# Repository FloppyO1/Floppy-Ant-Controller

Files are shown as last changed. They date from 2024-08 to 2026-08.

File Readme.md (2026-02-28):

# F.A.C. V2 - Floppy Ant Controller

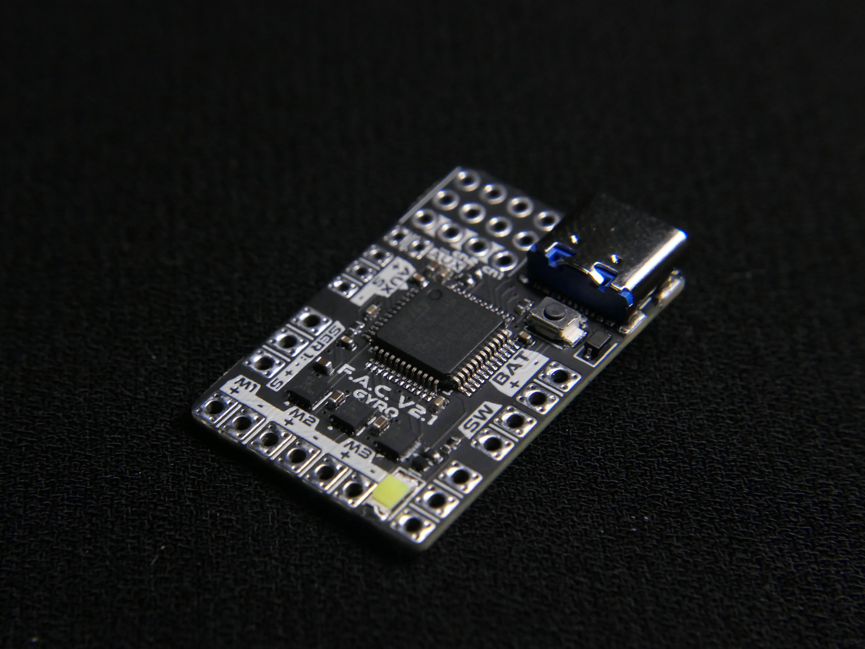
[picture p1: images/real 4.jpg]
FAC V2 front
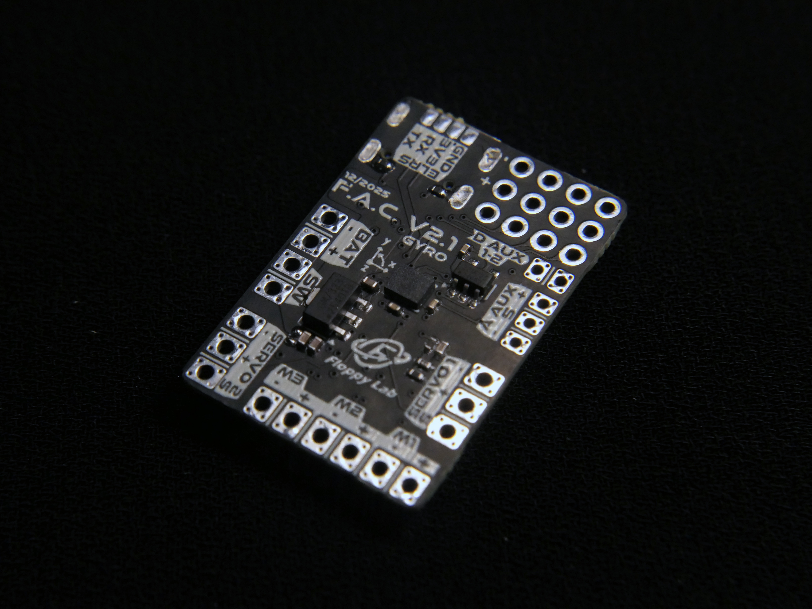
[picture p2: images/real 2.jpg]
FAC V2 rear
 

**F.A.C. V2** is an advanced control board specifically designed for combat robots (such as the Antweight category). Created by **Floppy Lab™**, it serves as a high-performance, highly customizable alternative to the Malenki-nano, offering professional features at a competitive price point.

## 🚀 Key Features

- **Full Customization**: All parameters are adjustable via USB using the dedicated [FAC Tool](https://factool.floppylab.it/).

- **Advanced Hardware**: Features a built-in **IMU** (accelerometer and gyroscope) for future firmware updates and advanced control algorithms.

- **Open Source**: Built with a community-first approach, allowing for user modifications and contributions.

- **Robust Safety**: Includes integrated Watchdog timers, Fail-Safe mechanisms, and Battery Cut-Off to protect your hardware.

## 📊 Technical Specifications

- **DC Motor Outputs**: 3 channels (1.8A max, 1000-step resolution, adjustable frequency 100Hz-10kHz).

- **Servo Outputs**: 2 HV channels (powered directly by the battery) with adjustable frequency and pulse width.

- **Inputs**: 2 Digital inputs and 1 Analog input (max 3.3V).

- **Power Supply**: Optimized for 1-2S LiPo batteries (up to 11V max).

- **Compact Form Factor**: 21mm x 31mm; weighs only 2.4g (bare board) 3.6g (with FS2A).

- **Receiver Compatibility**: Supports PWM (up to 4 channels) and PPM (up to 8 channels), ELRS (not implemented yet but ready to run on current hardware).

## 🛠️ Configuration (FAC Tool)

The **FAC Tool** provides a graphical interface for granular control over your robot's behavior:

1. **Mapping**: Freely assign software functions (e.g., Tank Mix) to physical pins on the board.

2. **Mixes & Special Functions**: Easily configure steering mixes or direct links between radio channels and outputs and others like DC servo.

3. **Real-time Telemetry**: Monitor battery voltage, radio signal values, and operational status (Armed/Disarmed/Cut-Off).

## ⚠️ Safety Information

- **Reverse Polarity**: The board **does not** have reverse polarity protection. Ensure the battery is connected correctly to avoid permanent damage.

- **Activation**: For safety, the FAC will not activate until it detects a valid signal from your receiver.

- **Battery Management**: Always configure the Battery Cut-Off to prevent over-discharging your LiPo cells.

## 📂 Project Structure

- `/FIRMWARE V2`: Firmware source code and binaries.

- `/docs`: Full English and Italian manual.

- `/HARDWARE V2`: Design files.

- `/TOOLS`: Usefull python tools, and the FAC jingle composer.

## 📦 Manufacturing

If you want to manufacture them by yourself you can do it directly from this link: [click here](https://www.pcbway.com/project/shareproject/Floppy_Ant_Controller_FAC_V2_The_Advanced_Control_Board_for_Combat_Robotics_f4803c5c.html)

Using this link you automatically help me with a small tip, without any additional costs. Thanks!

## 📩 Support & Feedback

Developed by **Floppy Lab™**. For suggestions, bugs, or feedback:

- **Email**: thefloppylab@gmail.com

- **Instagram**: [@the_floppy_lab](https://www.instagram.com/the_floppy_lab)

- **YouTube**: [@floppylab](https://www.youtube.com/@floppylab)

- **Website**: [www.floppylab.it](https://www.floppylab.it)

- **Support Me**: [PayPal](https://www.paypal.com/paypalme/FloppyLab)

---

*© 2026 The Floppy Lab™. All rights reserved.*

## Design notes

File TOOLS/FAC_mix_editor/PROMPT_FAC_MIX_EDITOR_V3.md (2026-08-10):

# F.A.C. Mix Editor — work order V3

**The robot stops being two numbers and becomes a machine you lay out.** A chassis
outline you draw, wheels you place and orient, an IMU that sits somewhere on it,
and a planar kinematic model that reads all of that instead of the two-sided
unicycle of §8.

Three changes to `TOOLS/FAC_mix_editor/FAC_mix_editor.html`. **No firmware change,
no generated-code change** — the `.c`/`.h` of every preset must come out
byte-identical, and that is a gate, not an aspiration.

Read `CLAUDE.md` in this folder first. Every invariant in it still holds unless
this document overrides it explicitly, and it overrides exactly one: the robot's
kinematics (§2) and the shape of `P.sim.robot` that goes with it.
`PROMPT_FAC_MIX_EDITOR_V2.md.old` is the previous work order, shipped; §8 in it is
the model this document replaces.

---

## Ground rules

- **Still one file.** No build step, no npm, no CDN, no font, no network call. It
  must keep working from `file://` with the console clean.
- **No second implementation.** This applies to the new solver too: the yaw-rate
  readout, the renderer's slip arrows and the simulator all call **the same
  `solveTwist()`**. A closed-form `maxSpeed / track` displayed next to a machine
  the solver disagrees with is the exact bug this rule exists to prevent.
- **No float in the graph math.** The float boundary count does not change: a
  gamepad axis in `PAD.padToStage0()`, and the robot's physical state in
  `SIM.robotImuCounts()`. The new model makes the second one richer, not looser —
  everything still dies in the same `Math.round` + int16 clamp, and the self-test
  still sweeps it.
- **The sensor model is not touched.** `SIM.sensorOffsets()`, the four noise/offset
  fields and their ODR hold stay exactly as they are. They now apply to counts
  produced by a better physical model; that is all.
- **The self-test is the contract.** Export stays blocked while it has not run or
  has a failure. Every § below adds assertions.
- **Keep the section banners.** The geometry and the solver get their own,
  `SECTION: ROBOT MODEL`, immediately before `SECTION: SIM` — `SIM` is large
  enough already, and the solver is pure and belongs where it can be read alone.
- Tabs, English identifiers and UI text, comments that say *why* and cite
  `file:line` of the firmware wherever they encode firmware behaviour.

---

## Decisions already taken — do not re-litigate

These came out of the design conversation. They are settled; if the implementation
finds one of them impossible, say so and stop, do not quietly pick the other side.

1. **The physics reads the wheels.** Not a drawing that decorates the old model.
2. **There is no wheel *type*.** A wheel has a **lateral grip** in `0…1`: `1` is a
   normal tyre, `0` is an omni/mecanum roller, in between is a track that scrubs.
   The omni case and the skid-slip case are the same parameter and must not become
   two.
3. **A wheel's steering angle may come from a servo row** of the mapper, so it
   changes while the mix runs.
4. **Servos are markers.** Position, mapper row, label, live value. No arm that
   rotates, no contribution to the motion. A wheel steered by a servo (3) is a
   property of the *wheel*, not a drawn servo.
5. **The IMU has a position on the chassis**, and off the centre of rotation it
   reads the centripetal and tangential terms that position implies.
6. **The chassis is a free polygon.** The body origin is the user's `(0,0)`, the
   point their coordinates are relative to — deliberately *not* the polygon
   centroid, which would slide the machine out from under them every time they
   moved a vertex.
7. **Both editors**: numbers in the Robot tab are the truth, dragging on the view
   is a shortcut onto the same fields.
8. **The three-motor-row ceiling stays** (`fac_settings.c:103-107`). The editor may
   describe a machine the firmware cannot drive today — a four-wheel mecanum needs
   four independent motor rows and there are three — and it must **say so** where
   the user picks the link, not hide it.

---

## Phases and order of work

**§1 → §2 → §3** in one commit each, in this order, and **stop after each one**.

- **§1 Model and migration.** Data model, migration, defaults, and every existing
  call site moved onto the new fields. Nothing visible changes.
- **§2 Kinematics, the IMU at a position, and the renderer.** The machine becomes
  real, and you can see it.
- **§3 The editors.** Numeric table, then dragging on the view.

§1 and §2 are fully verifiable headless. §3 is pointer interaction and **must be
checked in a browser by the user before it is called done** — `CLAUDE.md` records
what that costs when it is skipped.

---

## §0 — Verification protocol

`CLAUDE.md` § *Verifying a change without a browser* is the recipe: build the
throwaway node harness in the scratchpad, delete it afterwards, nothing
test-shaped gets committed. Re-read it rather than reinventing it — it lists the
four gotchas of the pure-section slice, the trap where an extracted function
missing a free variable silently does nothing, and the `Proxy` canvas smoke test.

This work order adds three gates on top of it:

- **The two standing regression gates are mandatory at every §**: the generated
  `.c`/`.h` of every preset diffed against `git show HEAD:...` with the
  `FAC_MIX_EDITOR_PROJECT` trailer stripped — **they must be identical, all 16
  files, at all three §** — and the `$('#id')`-versus-markup check (`selbox` is the
  known false positive).
- **Every new assertion gets mutation-tested.** Break what it covers on purpose,
  see it go red, put it back. An assertion that compares a value against the
  default it was derived from is not an assertion.
- **The kinematics is checked against closed forms, not against itself.** The
  three below are the acceptance core of §2 and are written out there in full:
  two parallel wheels reproduce today's numbers *exactly*; a four-wheel skid turns
  by the closed form `(sR−sL) / (2b + 2·g·a²/b)`; and an IMU at radius `r` on a
  machine spinning on the spot reads `ω²r` pointing at the centre.

---

## §1 — The model: a chassis, wheels, devices, an IMU

### The new `P.sim.robot`

```js
robot: {
    maxSpeedCms: 120,             /* ground speed of a wheel at full stick */
    shape: [[10,8],[10,-8],[-10,-8],[-10,8]],   /* cm, body frame, the outline */
    wheels: [                     /* order is the display order, nothing else */
        { x: 0, y: 7, deg: 0, grip: 1, link: 'M1', steer: '', steerDeg: 30, r: 3.5 }
    ],
    devices: [ { x: 8, y: 0, link: 'S1', label: '' } ],   /* markers only */
    imu: { x: 0, y: 0 },
    /* unchanged from §8 and the sensor model */
    imuSource, gyroNoise, accelNoise, gyroBias, accelBias, viewCm, follow, trail
}
```

A wheel: `x, y` cm in the body frame; `deg` its resting steering angle, `0` =
pointing forward; `grip` the lateral grip `0…1`; `link` the mapper row that drives
it, `''` for an undriven wheel (castor, idler, a trailing wheel that only carries
weight); `steer` a mapper row whose value steers it, `''` for a fixed wheel;
`steerDeg` the travel at full deflection; `r` the drawn radius.

**Removed**: `lenCm`, `widCm`, `trackCm`, `kin`, `left`, `right`, `leftB`,
`rightB`. Everything that read them moves onto the geometry:

- `robotScale()`'s auto-fit floor used `max(lenCm, widCm)` → a `chassisBounds()`
  helper over `shape`.
- the renderer's rectangle → the polygon.
- `SIM.sideDrive()` / `SIM.sideValue()` disappear; `solveTwist()` replaces them.
- the *max yaw* readout stops being `maxSpeed / track` and calls the solver (§2).

### Migration — and the one place it deliberately changes behaviour

`migrateProject()` stays pure and keeps building onto an untouched
`blankProject()`. It synthesises the new fields from the old ones:

- `shape` ← the rectangle `lenCm × widCm`, four vertices, centred on the origin.
- `imu` ← `{x: 0, y: 0}`.
- `wheels` ← from `kin`, `left`, `right`, `leftB`, `rightB`, at
  **`y = ±trackCm/2`** — the old physics used `trackCm` and nothing else, so this
  is what keeps an old project's numbers intact — with `deg: 0`, `grip: 1`,
  `steer: ''`.
  - `kin: 'diff'` → two wheels at **`x = 0`**. The result is *bit-for-bit* the old
    model, and the self-test asserts exactly that.
  - `kin: 'skid'` → four wheels at `x = ±0.22·lenCm`, which is where the old
    renderer drew them.
- any mapper row that was linked but not a drive side → a `devices` marker.

**A migrated four-wheel skid turns more slowly than it used to, and that is a
correction, not a regression.** The old model had no notion of a wheelbase at all:
four wheels on a rigid frame *do* resist yaw, in proportion to how far apart they
are along the machine. The self-test must pin the new value to the closed form of
§2, and the Robot tab must say it once, where the grip field is. Do not "fix" this
by migrating skid wheels to `x = 0`: that would hide a real property of the
machine to protect a number that was wrong.

### Done when

- `migrateProject()` is still pure and still merges onto defaults it never writes
  into; a partial `robot` block still defaults every field it omits.
- A schema-2 file with `kin: 'diff'` produces, over a 300-step scripted run, the
  **identical** pose string and the identical IMU counts as `git show HEAD:` does
  for the same file.
- A schema-1 file (no `sim.robot` at all) still loads and drives.
- Both standing gates pass.

---

## §2 — The kinematics, the IMU at a position, the renderer

### The solver

Body frame X forward, Y left, Z up — unchanged, and it is still a statement about
how the board is *mounted* (`enum AXIS`, `LSM6DS3.h:143-147`).

The body twist is `ξ = (vx, vy, ω)`. A wheel `i` at `r = (x, y)` with steering
angle `α` has contact velocity `u = (vx − ω·y, vy + ω·x)`, and two axes of its
own: rolling `d = (cos α, sin α)`, lateral `n = (−sin α, cos α)`.

Two weighted residuals per wheel:

```
rolling   (u·d − s)²  weight 1,     only for a wheel with a drive link
                                    s = deviceValue(link)/V_MAX * maxSpeedCms
lateral   (u·n)²      weight grip,  every wheel
```

with

```
a_roll = ( cos α, sin α,  x·sin α − y·cos α )     b = s
a_lat  = (−sin α, cos α,  x·cos α + y·sin α )     b = 0
```

Minimise the sum: the normal equations `M ξ = c`, `M = Σ w·a·aᵀ` (symmetric 3×3),
`c = Σ w·a·b`. Solve by explicit Cramer on the 3×3 — no library, no iteration —
with a **Tikhonov ridge `λ` added to the diagonal** so that a machine with no
wheels, one wheel, or grip `0` everywhere still yields a finite twist instead of
dividing by a zero determinant. The ridge is load-bearing, not defensive: a
two-wheel machine at grip `0` genuinely leaves `vy` unconstrained. Document the
chosen `λ` and assert that every degenerate layout still integrates finitely — the
renderer's smoke test throws on a non-finite coordinate and that is the point.

`solveTwist()` is **pure**: layout and commands in, `(vx, vy, ω)` plus the per-wheel
residuals out. `integrateRobot()` calls it and keeps everything else it does —
still after `runGraph()`, so a pass still reads the counts of the previous
millisecond.

### The three closed forms that must hold

**Two parallel wheels at `x = 0`, `y = ±b`, grip 1.** `M` comes out diagonal,
`(2, 2, 2b²)`, `c = (sL+sR, 0, b(sR−sL))`, so

```
vx = (sL+sR)/2      vy = 0      ω = (sR−sL)/(2b) = (sR−sL)/track
```

which is §8's model exactly. **This is the first assertion to write and the last
one to let fail.**

**Four wheels at `x = ±a`, `y = ±b`, grip `g`, all forward.** The lateral rows add
`4·g·a²` to `M[2][2]` and nothing else, so

```
ω = (sR − sL) / (2b + 2·g·a²/b)
```

The lateral grip fights the yaw with a term in the **wheelbase squared** — which
is exactly why a long tracked machine turns worse than a short one, and it is the
sentence the Robot tab should carry. `g = 0` returns the two-wheel answer.

**An omni wheel is `grip = 0`** and nothing else: its lateral row vanishes, the
machine gains a `vy`, and the same solver covers mecanum with no special case.

### The slip readout

The residuals are the slip, and they are already computed:
`u·n` per wheel is how fast that contact patch is being dragged sideways (cm/s),
`u·d − s` is how much it is spinning or being dragged along its own axis. Both are
reported per wheel; the renderer draws the lateral one as a short arrow at the
contact patch, and the panel shows the largest of them. Nothing is invented here —
if a number is not a residual of the solve, it does not go on screen.

### The IMU at a position

With the twist and its derivative, the accelerometer at `r = (x, y)` reads

```
a_x = v̇x − ω·vy − α·y − ω²·x
a_y = v̇y + ω·vx + α·x − ω²·y
```

where `α = dω/dt`. At `r = 0` with `vy = 0` this is `(v̇x, ω·vx)`, which is §8's
model — so the general form *contains* the old one and must be shown to.

`v̇x`, `v̇y` and `α` are all difference quotients over a 1 ms step, i.e. spikes of
hundreds of g on any stick movement, so **all three** go through the existing
`ROBOT_ACC_TAU` first-order lag, for the reason §8 already documents. Gyro Z is
still `ω`; gyro X and Y are still zero by construction, the sketch still being
planar.

**The analytic check:** spinning on the spot at constant `ω` with the IMU at
radius `r`, once the lag has settled, the accelerometer must read `ω²r` pointing
at the centre of rotation and nothing else. Assert the vector, not the magnitude —
the sign is the half that can be wrong.

### The renderer

`drawRobotView()` keeps its one-renderer-three-homes shape and its early return on
a zero-size host. What changes inside it:

- the chassis rectangle → `shape` as a closed path;
- each wheel drawn at its position, **rotated to its live steering angle**, sized
  by `r`, filled by the drive bar it already draws, with its lateral-slip arrow;
- devices as markers with their label and the value the mapper would send;
- the IMU as a small crosshair where it sits;
- the HUD gains the largest slip; it keeps the sensor-error tag and the view line.

Smoke-test it with the `Proxy` 2D context over the awkward shapes `CLAUDE.md`
lists, plus the new ones: no wheels, one wheel, a two-vertex "polygon", a wheel
100 m off the chassis, grip `0` everywhere, a steering row that is unlinked.

### Done when

- The three closed forms above hold as assertions.
- A `kin: 'diff'` project migrated from HEAD gives an identical 300-step pose
  string and identical IMU counts.
- Degenerate layouts produce finite numbers and the renderer draws them.
- The *max yaw* readout comes from `solveTwist()` and not from a formula.
- Both standing gates pass. **The generated code is still byte-identical.**

---

## §3 — The editors

### Numeric, in the Robot tab

A table per list — wheels, devices, chassis vertices — with add and remove, one
row per item, the fields of §1, and the derived physical readout beside the ones
that have one (a steering travel in degrees, a grip as *tyre / track / roller*).
The Robot tab already owns the simulator's theory and it keeps owning it: the
grip's meaning, the wheelbase-squared sentence, the migrated-skid correction and
the three-motor ceiling live there and nowhere else.

The list rebuild rule of `CLAUDE.md` applies and is the trap to avoid: **build the
shell once and re-render only the rows.** Rebuilding the panel on every keystroke
destroys the input being typed into and takes the focus and the caret with it.

`P.sim` is not on the undo stack — `applySnap()` restores nodes, wires, mode and
instances only — so the layout editor is not undoable either. That is consistent
with every other robot field; do not make this one list the exception.

### Dragging, on the view

Wheels, chassis vertices and the IMU are draggable on the robot canvas, writing
the same fields. Constraints that come from what is already there:

- **The panel drags itself by its header** (`rbDrag()`), and the canvas pans and
  follows. A drag that starts on a handle must be decided *first*, the way the
  editor's mousedown decides a pan before a node drag — get this wrong and moving
  a wheel moves the panel.
- Hit-testing is in world coordinates through the same `robotScale()` mapping the
  renderer uses. One mapping, both directions.
- A drag that starts on nothing is not a wheel drag.
- Grid snap: reuse the existing snap preference if it is meaningful here; if it is
  not, say so in the tab rather than inventing a second snap.

### Done when

- The numeric table survives typing into it — focus and caret intact.
- Every drag writes the same field the table writes, and the table shows it live.
- **Checked in a browser by the user**, on all three panel homes (floating,
  docked right, docked in the tab), with the pane collapsed and re-opened.
- Both standing gates pass.

---

## Appendix A — deliberately not in scope

- **Dynamics.** Still no mass, no inertia, no traction limit, no motor curve: a
  step on the stick is still a step in ground speed. The lateral grip is a
  *kinematic* weight, not a friction coefficient, and the Robot tab must not let
  anyone read it as newtons. The "illustrative, a kinematic sketch" caveat stays
  on screen.
- **A fourth motor row.** Out of scope here; it is a firmware change. The editor
  describes the machine, warns, and does not pretend.
- **Wheel radius as a gearing.** `r` is drawn size only. Ground speed comes from
  `maxSpeedCms` as it always has.
- **Suspension, camber, wheels off the ground.** Every wheel is in contact.
- **Undo for the layout.** See §3.

## Appendix B — what must not move

Checked at every §, and the first three are the ones that end the work if they
break:

1. The generated `.c`/`.h` of every preset, byte for byte.
2. The two float boundaries, and the int16 clamp at the second one.
3. A `kin: 'diff'` project's pose and IMU counts, against HEAD.
4. The sensor model: gaussian noise held at the 416 Hz ODR, per-run unit-drawn
   offsets, and `robotImuCounts()` pure and deterministic.
5. `migrateProject()` pure, building onto defaults it never writes into.
6. The view as a fixed window on the ground, pixels only.
7. One copy of each explanation: block theory in the *Blocks* tab, simulator
   theory in the *Robot* tab, shortcuts in the help modal.

## Suggested commit messages

```
mix editor: §1 the robot becomes a layout - chassis, wheels, devices, IMU position
mix editor: §2 planar kinematics from the wheels, IMU off-centre, new renderer
mix editor: §3 the layout editors - numeric table and dragging on the view
```

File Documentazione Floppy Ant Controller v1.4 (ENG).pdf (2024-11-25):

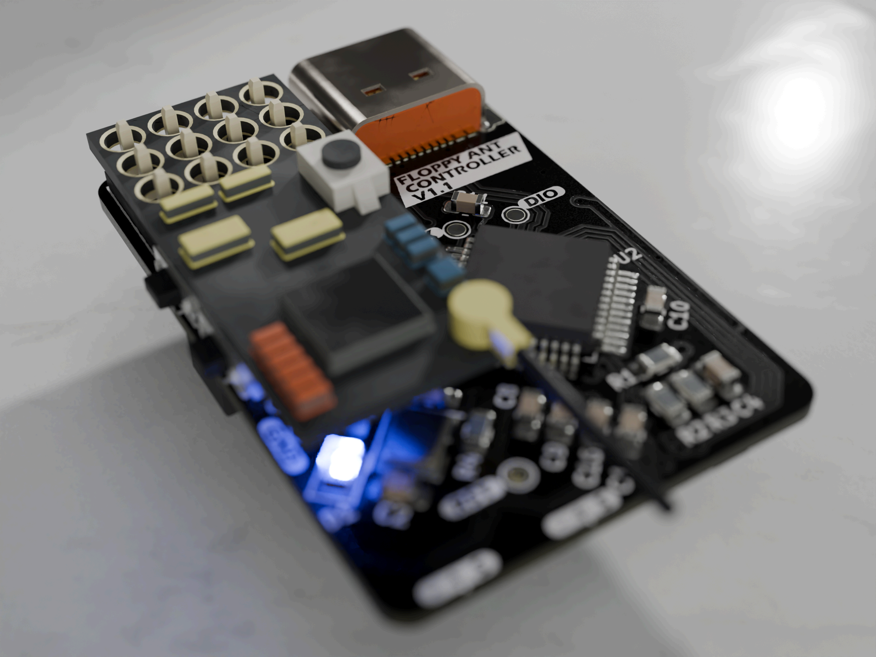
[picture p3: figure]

# Floppy Ant Controller V1.3

### last update 08/2024

─

## This is the documentation in which the functions and methods of use of the Floppy Ant Controller (version

1.3) will be explained.
rev: 1.4 | thefloppylab@gmail.com

Definitions | 2
Overview | 2
Specifications | 2
Connections, buttons and LEDs | 3
Settings and FAC Settings Tool 2.0 | 4
Settings | 4
Connection to PC/smartphone with Serial Monitor | 5
Composition of a command | 5
Changing settings with the FAC Settings Tool 2.0 | 6
FAC capabilities and limitations | 7
More information | 8
rev: 1.0 thefloppylab@gmail.com | 1

## Definitions

1. FAC: Short for Floppy Ant Controller.
2. Tank mix: mixing of the channels to move the wheels with the same logic as the tracks of a tank.
3. BEC: alternative power source, in fact it is a buck converter that lowers the voltage from the battery (2S) down to 5V (3A peak maximum).
4. Pad: where wires can be soldered to make the various electrical connections.

## Overview

In this document you will find all the information necessary to use the Floppy Ant Controller version 1.3.
The methods of use are almost the same for all versions, there are only some variations in the settings and the position of the connection points of the external components.
The FAC has been designed to combine perfectly with the FS2A receivers, excellent for being associated with the economical FlySky-i6 and FS-i4 radio controls, so as to also be accessible for those who do not already have more advanced radio systems.
Obviously no one forbids connecting other types of receivers, the important thing is that they have a PPM or PWM output, this limit is currently dictated by the firmware and part of the hardware.
To make it easy to use, a PC program called FAC Settings Tool (https://github.com/FloppyO1/Floppy-Ant-Controller/blob/main/SOFTWARE/FAC%20Settings%20Tool%202.0.exe) which allows you to easily modify, export and import all the settings of the Floppy Ant Controller.

## Specifications

- 3x DC motor drivers (200 speed steps).
- 2x servo outputs (one of which can be selected with a solder jumper whether 5V or HV from battery).
- Servo output signal frequency 200Hz.
- BEC 5V, 3A maximum (great for a servo motor).
- 2x expansion ports with possible digital or analog readout (e.g. potentiometers, switches, etc.).
- Support for 1s and 2s batteries.

- Battery voltage reading, with weapon speed limitation threshold and full shutdown threshold (independent).
- Settings can be set via USB with dedicated
software or serial terminal.
- Compatibility with 4 PWM channels and 8 PPM channels.
- Dimensions of 23mm*33mm for a weight of 2.9g (without receiver).

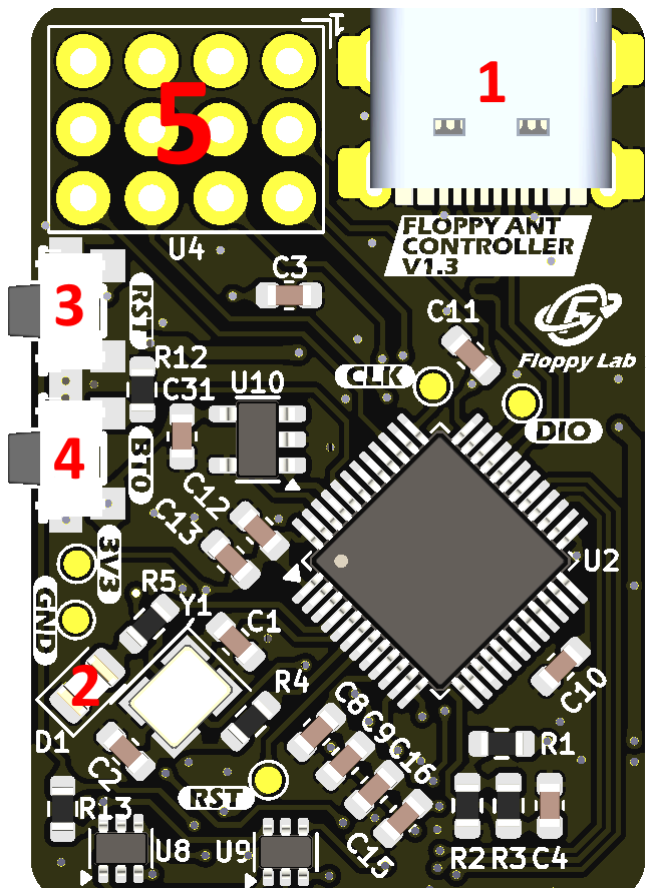
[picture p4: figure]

## Connections, buttons and LEDs

- The USB-C connector

1 allows the connection of the board to the PC to: change the settings, or update the firmware.
- The status LED
2

(D1) indicates what state the FAC is in, therefore whether it is in normal, cutoff or limit operation.
- The RESET buttons

3 e BOOT
4

they are used to start
the bootloader and update the FAC firmware.
- The holes

5 which form a 4*3 matrix, are the ones where the receiver must then be soldered.
- In the pad

6 with the Li-Po label, is where the battery cables must be connected.
- In the SW pad
7

the main switch must be connected, it completely disconnect the battery from the rest of the circuit.
- The pads M1
8

, M2
9

, M3

10 are connected to the DC motor drivers, the outputs have the maximum voltage of the battery, and a supported current of 2A (DRV8838 driver).
- At the bottom are the servo pads
11

, the left one
allows you to choose the output voltage of the power supply, between 5V (from the BEC) and VBAT (directly from the battery), by soldering the jumper

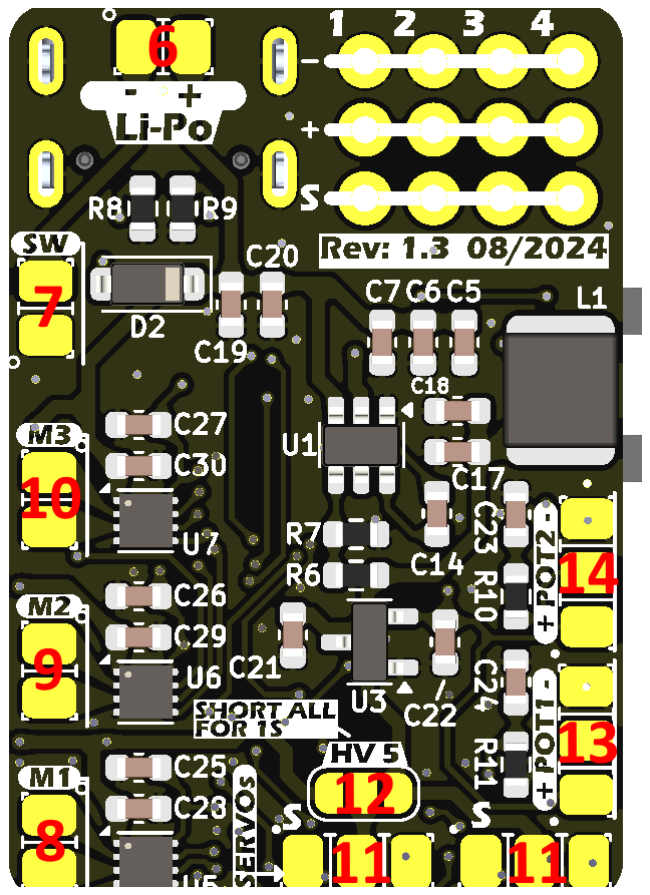
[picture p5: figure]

12 a little higher. The other servo output is only 5V. Both have a 0-5V logic signal.
- Pads POT1

13 and POT2

14 allow you to connect external potentiometers or switches to implement additional functions such as controlling the position of an arm.

## Settings and FAC Settings Tool 2.0

The board’s functionality can be changed by connecting the FAC via USB-C to your PC or smartphone and changing its settings.
The FAC settings are saved in an EEPROM memory, so once the power is disconnected they remain stored, so it is not necessary every time change them when turned on the FAC.

## Settings

Below are all the commands (i.e. settings) and their descriptions in a table.
COMMAND (with default values) | Valid Values | DESCRIPTION
TH2CH>2 | 1 - 8 | Channel assignment to the throttle
ST2CH>4 | 1 - 8 | Channel assignment to steering
WP2CH>3 | 1 - 8 | Channel assignment to the weapon
S12CH>6 | 1 - 8 | Channel assignment to servo output 1
S22CH>1 | 1 - 8 | Channel assignment to servo output 2
ARM2CH>5 | 1 - 8 | Arming channel assignment
M1REV>1 | 0, 1 1 | Reverses motor 1
M2REV>1 | 0, 1 1 | Reverses motor 2
M3REV>0 | 0, 1 1 | Reverses motor 3
S1REV>0 | 0, 1 1 | Reverses servo 1
S2REV>1 | 0, 1 1 | Reverses servo 2
M1ASS>ML | ML, MR, WP 2 | Assign motor 1 the left motor (DC motor)
M2ASS>MR | ML, MR, WP 2 | Assign motor 2 the right motor (DC motor)
M3ASS>WP | ML, MR, WP 2 | Assign motor 3 to the weapon motor (DC motor)
WPDD>0 | 0, 1 1 | The weapon has two directions not just one (DC motor)
TNCON>1 | 0, 1 1 | Tank mix activated
NODISARM>0 | 0, 1 1 | No disarm channels (automatic arming active)
VOLIM>28 (= 2.8V) | 0 - 42 | Weapon speed limiting voltage (voltage per cell)
VCUTOFF>35 (= 3.5V) | 0 - 42 | Total robot deactivation voltage (voltage per cell)
RXPWM>0 | 0, 1 1 | Receiver signal is PWM type (otherwise PPM)
1. In commands with valid values 0 and 1, one is equivalent to “active”, zero equals “deactivated”.
2. With motor assignment commands (MxASS>xx), you cannot assign two motors (M1, M2, M3) with the same type (ML, MR, WP).

READ | Reads the settings from EEPROM and prints them on the serial monitor (if it is sent it overwrites the changes made)
SAVE | Save all settings in EEPROM
CON | It does nothing and is only used for the FAC Settings Tool

## Connection to PC/smartphone with Serial Monitor

Commands can be sent via serial after connecting to the FAC with a serial monitor. This method allows you to set all the values to your liking, though non no check is made that the entered value is valid, therefore use this method with caution when changing settings. You can connect via PC with any serial monitor software (such as Termite, (https://translate.google.com/website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) or that of Arduino IDE), you just need to connect the USB, select the correct port and a baud rate to your liking (the FAC adapts accordingly). Once connected you can send commands.
The same thing applies to the smartphone, you can download an application that manages serial communication (such as Serial USB Terminal, (https://translate.google.com/website?sl=it&tl=en&hl=it&client=webapp) excellent because it allows you to save predefined commands) and connect to the FAC as described before. If it doesn't recognize your board, it's most likely because the cable/adapter you used is not OTG.

## Composition of a command

A command is made up of two parts: the first is the type, the second the value. They are separated by the '>' character. For example, if we want the tank mix throttle to be connected to channel 3 of our radio control, we must send: TH2CH>3.
If the FAC understands the command you just sent it responds with “OK”, otherwise with “WHAT??”
To view the settings saved in the FAC EEPROM, you can send the READ command. Please note that when this command is sent, the settings you have previously changed are overwritten with those read from the EEPROM.
Once you have changed the settings, to save them simply send the SAVE command and make sure that the OK response appears, which indicates correct receipt of the command.

## Changing Settings with “FAC Settings Tool 2.0”

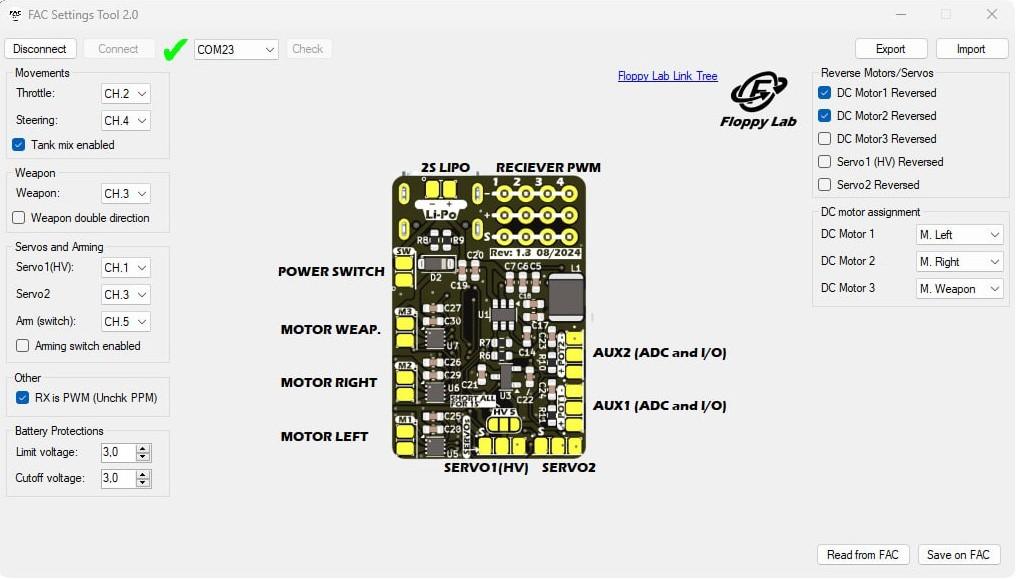
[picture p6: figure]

The FAC Settings Tool 2.0 makes changing FAC settings more intuitive and faster.
On the sides of the application (currently available only for Windows) there are all the settings previously listed in the table. Furthermore, it allows you to export and import settings in a .csv file, so you can save configurations you create, and if necessary they can be easily shared.
1. Once the tool has been opened and the FAC connected to the PC, click on the "Check" button at the top left of the application, and select the correct port with the drop-down menu.
2. Once selected, press the “Connect” button and wait for the green check to appear next to the button you just pressed.
a. If a window appears with an error message, it means that the selected port does not correspond to the FAC, but to some other device. In this case select a different port and press “Connect” again.
3. As soon as the FAC connects all the settings are loaded and the graphics are updated.
4. Now you can change the settings to your liking.
5. Once you are satisfied with the setup, at the bottom right you can click the “Save on FAC” button and wait for the saving to complete.
6. If you want to export or import your settings, simply press the “Export” or “Import” buttons and save the file with the name you prefer.

## FAC capabilities and limitations

The FAC is designed to be used with 150g robots, so the performance of the DC drivers and BEC is limited.
1. The three drivers for the DC motors are designed to operate up to a voltage of 12V, and a peak current of 1.9A (the driver used is the DRV8838, the same as Malenki nano) (https://github.com/MarkR42/malenki-nano.git) so they are great for running N20 motors.
2. The status LED together with the sounds played by the DC motors indicate the status of the board. When the board is working normally, the LED flashes with a period of 1 second. If the board is not armed one of the motors emits a "beep", otherwise no sound is emitted.
3. The card allows you to set arming, i.e. if the robot is not armed all its functions are deactivated (wheels and weapon stopped, servo position 0). If arming via the remote control channel is not active (activated from settings), the FAC is already armed as soon as it is switched on and cannot be disarmed.
If a dedicated channel is used for arming, the FAC can be disarmed whenever you want.
4. The FAC integrates the battery voltage reading. The reading may be inaccurate due to component tolerances.
Two (independent) thresholds can be set which are activated 10 seconds after the battery voltage drops below them:
a. The first (Limit) limits the speed of the weapon (only if DC motor) to 50% of the speed, so as to extend the battery life during the fight.
b. The second (Cut-Off) completely disables the robot, this threshold is usually very low, and serves to preserve the health of the batteries. When the robot is in Cut-Off the status LED flashes quickly.
5. The BEC is effectively a buck converter, which is designed to withstand a maximum current of 3A (better to stick to a maximum of 2.5A). Therefore, when servo motor outputs are used, I strongly recommend not using two servos powered by the BEC and not connecting ESCs with BLDC motors, as this may result in malfunctions and breakage of the BEC and the rest of the board, making it unusable.
To overcome this problem, you can use a 5V servo (i.e. from the BEC) and an HV servo by soldering the jumper in the marked part.

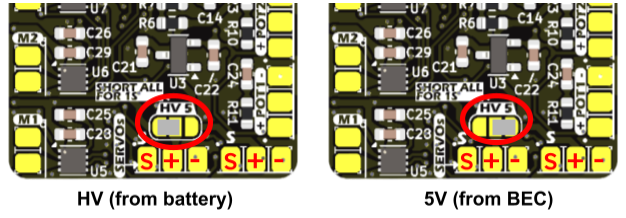
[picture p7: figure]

6. The FAC can be powered at a maximum voltage of 8.4V, therefore a 2S battery. This limitation is due to the maximum voltage of the DC motor drivers, and the battery voltage reading.
7. To use a FAC with a 1S battery, you can short (as marked on the board) the three servo motor voltage selection pads, so the input and output of the BEC are shorted, so the BEC stays off. Be very careful not to power more than 5V when using this configuration, otherwise the board will burn out.
8. Be careful, when the FAC is connected to the PC all systems are also active, including the DC drivers and servo motors.

## Firmware update

- To update the FAC firmware, you need to use a tool called STM32CubeProgrammer downloadable from the ST Microelectronics (https://github.com/FloppyO1/Floppy-Ant-Controller/blob/main/SOFTWARE/FAC%20firmware%201.3.elf) website (I recommend downloading version 2.15.0).
- Once you have downloaded the Cube Programmer, on the project GitHub page, inside the “SOFTWARE” folder, you need to download the “FAC firmware.elf” (https://github.com/FloppyO1/Floppy-Ant-Controller/blob/main/SOFTWARE/FAC%20firmware%201.3.elf) file which is the file to upload to the FAC.
- Once you have downloaded the .elf file, open Cube Programmer and connect the FAC with a data cable to the PC.
- Now we activate the FAC bootloader, to do this you need to press both buttons on the side of the FAC, and first release the RESET

1 button, then you can also release

the other one
2

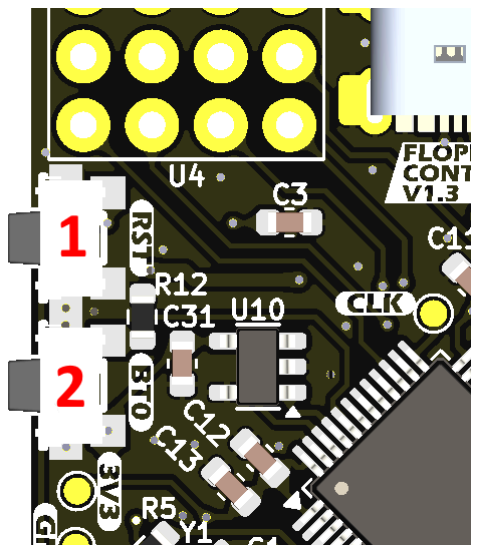
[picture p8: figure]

- The green light on the FAC should no longer light up, and you should hear the classic sound of inserting a USB device.
- On CubeProgrammer select USB from the drop-down menu at the top right next to the “Connect” button, then click the refresh button to find the port to connect to, it should appear next to where it said “No DFU…”. After finding it, press Connect and wait for some writing to appear in the middle of the screen.

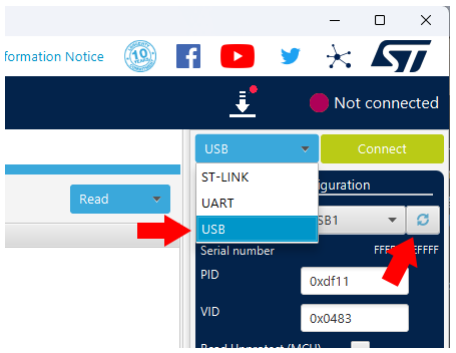
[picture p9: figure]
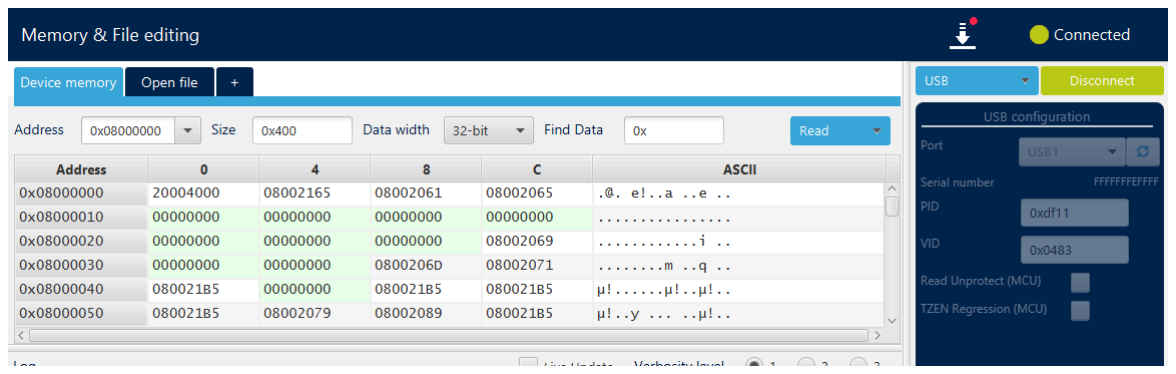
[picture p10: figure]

- Press the second icon on the left of the screen, and then by clicking the “Browse” button select the “FAC firmware.elf” file that you downloaded earlier. Add the check mark on “Verify programming” and “Run after programming”.

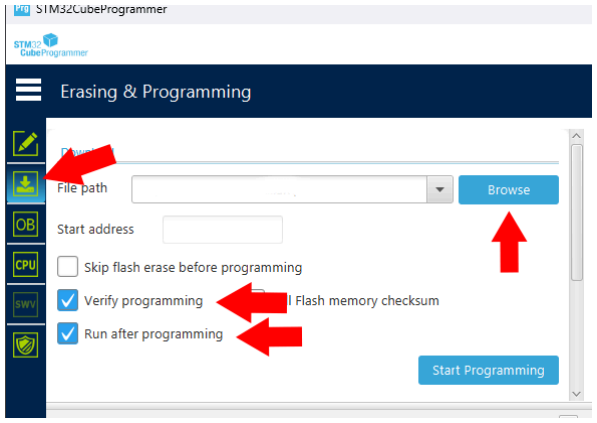
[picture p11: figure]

- Now all that remains is to press the “Start Programming” button, once the program has finished loading the FAC should restart and the light will start flashing slowly again.
Your FAC firmware is now updated to the latest version available!

## More information

The entire project is open source, and you can find all the files on this GitHub page. (https://github.com/FloppyO1/Floppy-Ant-Controller) For any questions or requests do not hesitate to send an email to: thefloppylab@gmail.com.

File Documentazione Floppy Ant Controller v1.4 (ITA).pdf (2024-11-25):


# Floppy Ant Controller V1.3

### ultimo aggiornamento 08/2024

─

## Questa è la documentazione in cui verranno spiegate le funzionalità e la modalità d’uso della Floppy Ant

Controller (versione 1.3).

rev: 1.4 | thefloppylab@gmail.com

Definizioni | 2
Panoramica | 2
Specifiche | 2
Connessioni, pulsanti e LED | 3
Impostazioni e FAC Settings Tool 2.0 | 4
Impostazioni | 4
Connessione al PC/smartphone con Monitor Seriale | 5
Composizione di un comando | 5
Modifica delle impostazioni con il “FAC Settings Tool 2.0” | 6
Aggiornamento del firmware | 7
Capacità e limitazioni della FAC | 7
Altre informazioni | 8
rev: 1.0 thefloppylab@gmail.com | 1

## Definizioni

1. FAC: abbreviazione di Floppy Ant Controller.
2. Tank mix: mixing dei canali per muovere le ruote con la stessa logica dei cingoli di un carro armato.
3. BEC: fonte di alimentazione alternativa, di fatto è un buck converter che abbassa la tensione dalla batteria (2S) fino a 5V (3A picco massimi).
4. Pad: piazzola dove si possono saldare dei fili per effettuare le varie connessioni elettriche.

## Panoramica

In questo documento troverete tutte le informazioni necessarie per poter utilizzare la Floppy Ant Controller versione 1.3.
Le modalità d’uso sono pressoché uguali per tutte le versioni, ci sono solo alcune variazioni nelle impostazioni e la posizione dei punti di connessione dei componenti esterni.
La FAC è stata pensata per combinarsi perfettamente con i ricevitori FS2A, ottimi per essere associati agli economici radiocomandi FlySky-i6 e FS-i4, così da essere anche accessibile per chi non è già in possesso di sistemi radio più avanzati.
Ovviamente nessuno vieta di collegare altri tipi di ricevitori, l’importante è che abbiano una uscita PPM o PWM, questo limite è per ora dettato dal firmware e parte del hardware.
Per renderla facile da usare, è stato realizzato un programma per PC chiamato FAC Settings Tool (https://github.com/FloppyO1/Floppy-Ant-Controller/blob/main/SOFTWARE/FAC%20Settings%20Tool%202.0.exe) che permette di modificare, esportare e importare agevolmente tutte le impostazioni della Floppy Ant Controller.

## Specifiche

- 3x driver per motori DC (200 passi di velocità).
- 2x uscite servo (una delle quali può essere selezionata con un ponticello a saldare se 5V o HV dalla batteria).
- Frequenza del segnale delle uscite servo 200Hz.
- BEC 5V, 3A massimi (ottimi per un servo motore).
- 2x porte di espansione con possibile lettura digitale o analogica (es. potenziometri, interruttori, ecc.).
- Supporto per batterie da 1s e 2s.

- Lettura della tensione della batteria, con soglia di limitazione della velocità dell'arma e soglia di spegnimento completo (indipendenti).
- Le impostazioni possono essere impostate tramite
USB con software dedicato o terminale seriale.
- Compatibilità con 4 canali PWM e 8 canali PPM.
- Dimensioni di 23mm*33mm per un peso di 2,9g (senza ricevente).


## Connessioni, pulsanti e LED

- Il connettore USB-C

1 permette la connessione della scheda al PC per: modificare le impostazioni, oppure l’aggiornamento del firmware.
- Il LED di stato
2

(D1) indica in che stato è la FAC, quindi se è in operazione normale, cutoff o limit.
- I pulsanti di RESET

3 e BOOT

4 servono per poter
avviare il bootloader e aggiornare il firmware della FAC.
- I fori

5 che formano una matrice 4*3, sono quelli dove va poi saldato il ricevitore.
- Nel pad

6 con l’etichetta Li-Po vanno collegati i cavi della batteria.
- Nel pad SW⁷ va collegato l’interruttore generale che scollega completamente la batteria dal resto del circuito.
- Nei pad M1
8

, M2
9

, M3

10 sono collegati ai driver dei motori DC, le uscite hanno come tensione massima quella della batteria, e una corrente supportata di 2A (driver DRV8838).
- In basso si trovano i pad dei servo
11

, il primo
permette di scegliere la tensione di uscita dell’alimentazione, tra 5V (dal BEC) e VBAT
(direttamente dalla batteria), saldando il ponticello
12


poco più in sopra. La seconda uscita del servo è soltanto 5V. Entrambe hanno un segnale logico 0-5V.
- I pad POT1

13 e POT2

14 permettono di collegare dei potenziometri o degli interruttori esterni per poter implementare funzioni aggiuntive come il controllo della posizione di un braccio.

## Impostazioni e FAC Settings Tool 2.0

Le funzionalità della scheda possono essere modificate collegando la FAC via USB-C al PC o allo smartphone e modificando le sue impostazioni.
Le impostazioni della FAC sono salvate in una memoria EEPROM, quindi una volta scollegata l’alimentazione rimangono memorizzate, così non è necessario ogni volta cambiarle all’accensione.

## Impostazioni

Di seguito sono riportati in una tabella tutti i comandi (ovvero le impostazioni) e la loro descrizione.
COMANDO (con valori default) | Valori Validi | DESCRIZIONE
TH2CH>2 | 1 - 8 | Assegnazione del canale all’acceleratore
ST2CH>4 | 1 - 8 | Assegnazione del canale allo sterzo
WP2CH>3 | 1 - 8 | Assegnazione del canale all’arma
S12CH>6 | 1 - 8 | Assegnazione del canale all’uscita del servo 1
S22CH>1 | 1 - 8 | Assegnazione del canale all’uscita del servo 2
ARM2CH>5 | 1 - 8 | Assegnazione del canale di arming (attivazione)
M1REV>1 | 0, 1 1 | Inverte il motore 1
M2REV>1 | 0, 1 1 | Inverte il motore 2
M3REV>0 | 0, 1 1 | Inverte il motore 3
S1REV>0 | 0, 1 1 | Inverte il servo 1
S2REV>1 | 0, 1 1 | Inverte il servo 2
M1ASS>ML | ML, MR, WP 2 | Assegna al motore 1 il motore sinistro (motore DC)
M2ASS>MR | ML, MR, WP 2 | Assegna al motore 2 il motore destro (motore DC)
M3ASS>WP | ML, MR, WP 2 | Assegna al motore 3 il motore dell’arma (motore DC)
WPDD>0 | 0, 1 1 | L’arma ha due direzioni non solo una (motore DC)
TNKON>1 | 0, 1 1 | Attivato il tank mix
NODISARM>0 | 0, 1 1 | Nessun canale di arming (arming automatico attivo)
VLIM>28 (= 2.8V) | 0 - 42 | Tensione di limitazione velocità arma (tensione per cella)
VCUTOFF>35 (= 3.5V) | 0 - 42 | Tensione di disattivazione totale del robot (tensione per cella)
RXPWM>0 | 0, 1 1 | Segnale del ricevitore in PWM
1. Nei comandi con valori validi 0 e 1, uno equivale ad “attivo”, zero equivale “disattivato”.
2. Nei comandi di assegnazione dei motori (MxASS>xx), non si può assegnare a due motori (M1, M2, M3) con lo stesso tipo (ML, MR, WP).

READ | Legge da EEPROM le impostazioni e le stampa sul monitor seriale (se viene inviato sovrascrive le modifiche effettuate)
SAVE | Salva tutte le impostazioni in EEPROM
CON | Non fa nulla è utilizzato solo per il FAC Settings Tool

## Connessione al PC/smartphone con Monitor Seriale

Ii comandi si possono inviare via seriale dopo essersi connessi alla FAC con un monitor seriale. Questo metodo vi permette di impostare tutti i valori a vostro piacimento, però non viene effettuato nessun controllo che il valore immesso sia valido, quindi usate con cautela questo metodo per la modifica delle impostazioni.
Potete collegarvi via PC con un qualsiasi software di monitor seriale (come Termite, (https://translate.google.com/website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) oppure quello di Arduino IDE), è necessario solo collegare la USB, selezionare la porta corretta e un baudrate a vostro piacimento (la FAC si adegua di conseguenza). Una volta collegati potete inviare i comandi.
La stessa cosa si applica allo smartphone, potete scaricare una applicazione che gestisce la comunicazione seriale (come Serial USB Terminal, (https://translate.google.com/website?sl=it&tl=en&hl=it&client=webapp) ottima perché permette di salvare dei comandi predefiniti) e collegarvi come descritto prima alla FAC. Se non vi riconosce la scheda, molto probabilmente è perché il cavo/adattatore che avete usato non è OTG.

## Composizione di un comando

Un comando è composto da due parti: la prima è il tipo, la seconda il valore. Esse sono separate dal carattere ‘>’. Per esempio se vogliamo che l’acceleratore del tank mix sia collegato al canale 3 del nostro radiocomando dobbiamo inviare: TH2CH>3.
Se la FAC capisce il comando che avete appena inviato vi risponde con “OK”, altrimenti con “WHAT??”
Per visualizzare le impostazioni salvate nella EEPROM della FAC, si può inviare il comando READ. Fate attenzione che quando viene inviato questo comando, le impostazioni che avete modificato in precedenza vengono sovrascritte con quelle lette dalla EEPROM. Una volta modificate le impostazioni, per salvarle basta inviare il comando SAVE ed assicurarsi che appaia la risposta OK, che indica il corretto ricevimento del comando.

## Modifica delle impostazioni con il “FAC Settings Tool 2.0”


Il FAC Settings Tool 2.0 rende più intuitiva e veloce la modifica delle impostazioni della FAC. Ai lati dell’applicazione (per ora disponibile solo per Windows) sono presenti tutte le impostazioni prima elencate nella tabella. In più permette di esportare e importare le impostazioni in un file .csv, così da poter salvare delle configurazioni da voi create, e in caso di necessità sono facilmente condivisibili.
1. Una volta aperto il tool e collegata al PC la FAC, cliccare sul pulsante “Check” in alto a sinistra dell’applicazione, e selezionare la porta corretta con il menu a tendina.
2. Una volta selezionata premere il pulsante “Connect” e attendere che appaia la spunta verde in fianco al pulsante appena premuto.
a. Nel caso in cui appaia una finestra con un messaggio di errore, vuol dire che la porta selezionata non corrisponde alla FAC, ma a qualche dispositivo. In questo caso selezionate una porta differente e premete ancora “Connect”.
3. Non appena la FAC si connette vengono caricate tutte le impostazioni e vengono aggiornate le grafiche.
4. Ora potete modificare le impostazioni a vostro piacimento.
5. Una volta soddisfatti del setup, in basso a destra potete cliccare il pulsante “Save on FAC” e attendere che il salvataggio venga completato.
6. Se volete esportare o importare le vostre impostazioni è sufficiente premere i pulsanti “Export” o “Import” e salvare il file con il nome che preferite.

## Capacità e limitazioni della FAC

La FAC è pensata per essere utilizzata con dei robot da 150g, per questo le prestazioni dei driver DC e del BEC sono limitate.
1. I tre driver per i motori DC sono progettati per funzionare fino ad una tensione di 12V, e una corrente di picco di 1.9A (il driver usato è il DRV8838, lo stesso della Malenki nano) (https://github.com/MarkR42/malenki-nano.git) quindi sono ottimi per gestire motori N20.
2. Il LED di stato insieme ai suoni riprodotti dai motori DC indicano lo stato della scheda. Quando la scheda funziona normalmente, il LED lampeggia con un periodo di 1 secondo. Se la scheda non è armata uno dei motori emette un “beep”, altrimenti nessun suono viene emesso.
3. La scheda permette di impostare l’arming, ovvero se il robot non è armato tutte le sue funzionalità sono disattivate (ruote e arma ferma, servo posizione 0). Se l’arming tramite canale del telecomando non è attivo (attivabile dalle impostazioni), la FAC non appena viene accesa è già armata e non è possibile disarmarla.
Nel caso in cui si utilizzi un canale dedicato per l’arming, la FAC si può disarmare e armare a piacimento.
4. La FAC integra la lettura della tensione della batteria. La lettura può essere imprecisa causa tolleranze dei componenti.
Si possono impostare due soglie (indipendenti) che si attivano dopo 10 secondi che la tensione della batteria scende sotto di esse:
a. la prima (Limit) limita la velocità dell’arma (solo se motore DC) al 50% della velocità, così da allungare la durata della batteria durante il fight.
b. la seconda (Cut-Off) disabilita completamente il robot, questa soglia è solitamente molto bassa, e serve per preservare la salute delle batterie. Quando il robot è in Cut-Off il LED di stato lampeggia velocemente.
5. Il BEC è di fatto un buck converter, che è progettato per sopportare una corrente massima di 3A (meglio rimanere su massimo 2.5A). Quindi quando vengono utilizzate le uscite dei servomotori, consiglio vivamente di non utilizzare due servo alimentati dal BEC e di non collegare degli ESC con motori BLDC, in quanto si possono avere malfunzionamenti e rottura del BEC e il resto della scheda, rendendola inutilizzabile.
Per ovviare a questo problema, si possono utilizzare un servo alimentato a 5V (ovvero dal BEC) e uno HV saldando il ponticello nella parte segnata.


6. La FAC può essere alimentata ad una tensione massima di 8.4V, quindi una batteria 2S. Questa limitazione è dovuta dalla tensione massima dei driver dei motori DC, e dalla lettura della tensione della batteria.
7. Per utilizzare una FAC con una batteria 1S, si può mettere in cortocircuito (come segnato sulla scheda) i tre pad della selezione della tensione del servomotore, così l’entrata e l’uscita del BEC vengono cortocircuitate, quindi il BEC rimane spento. Fate molta attenzione a non alimentare a più di 5V quando usate questa configurazione, altrimenti la scheda si brucia.

### 8. Fate attenzione, quando la FAC è collegata al PC anche tutti i sistemi sono

attivi, compresi i driver DC che i servomotori.

## Aggiornamento del firmware

- Per aggiornare il firmware della FAC, è necessario utilizzare un tool chiamato STM32CubeProgrammer scaricabile dal sito della ST Microelectronics (https://www.st.com/en/development-tools/stm32cubeprog.html) (consiglio di scaricare la versione 2.15.0).
- Una volta scaricato il Cube Programmer, nella pagina GitHub del progetto, all’interno della cartella “SOFTWARE”, bisogna scaricare il file “FAC firmware.elf” (https://github.com/FloppyO1/Floppy-Ant-Controller/blob/main/SOFTWARE/FAC%20firmware%201.3.elf) che è il file da caricare sulla FAC.
- Una volta scaricato il file .elf, aprire Cube Programmer e collegare la FAC con un cavo dati al PC.

- Ora attiviamo il bootloader della FAC, per farlo bisogna premere entrambi i pulsanti a lato della FAC, e rilasciare per primo il pulsante di RESET
1

, poi si può rilasciare
anche l’altro
2


- La luce verde della FAC non dovrebbe più accendersi, e si dovrebbe sentire il classico suono di inserimento di un dispositivo USB.
- Su Cube Programmer selezionare in alto a destra, in fianco al pulsante “Connect”, “USB” dal menu a tendina, poi sotto cliccare il pulsante aggiorna per trovare la porta a cui connettersi, dovrebbe apparire in fianco dove c’era scritto “No DFU…”. Dopo averla trovata premere su “Connect” e attendere che appaiano delle scritte in mezzo allo schermo.

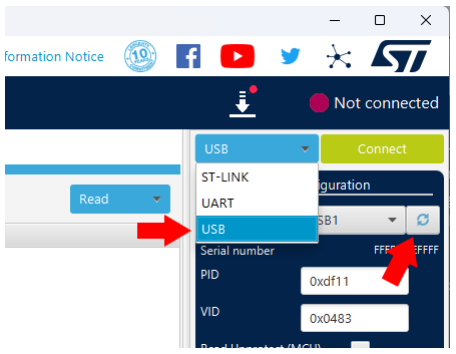
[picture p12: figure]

- Premere sulla seconda icona che si trova sulla sinistra della videata, e poi cliccando sul pulsante “Browse” selezionare il file “FAC firmware.elf” che avete scaricato prima.

Aggiungere la spunta su “Verify programming” e “Run after programming”.


- Ora resta solo premere sul pulsante “Start Programming”, finito di caricare il programma la FAC dovrebbe riavviarsi e la luce riprende a lampeggiare lentamente. Il firmware della vostra FAC è ora aggiornato all’ultima versione disponibile!

## Altre informazioni

Tutto il progetto è open source, e trovate tutti i file su questa pagina GitHub. (https://github.com/FloppyO1/Floppy-Ant-Controller) Per ogni domanda o richiesta non esitate ad inviare una mail all’indirizzo: thefloppylab@gmail.com.

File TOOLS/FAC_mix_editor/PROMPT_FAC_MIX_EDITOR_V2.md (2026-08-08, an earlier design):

# F.A.C. Mix Editor — work order V2

Ten changes to `TOOLS/FAC_mix_editor/FAC_mix_editor.html`, plus one coordinated
firmware fix in the `FIRMWARE V2/FAC-Firmware-V2` submodule.

Read `CLAUDE.md` in this folder first, and `PROMPT_FAC_MIX_EDITOR.md.initial` for
anything this document does not cover. Every invariant in `CLAUDE.md` still holds
unless this document overrides it explicitly, and it overrides exactly one thing:
the channel domain (§1).

**This document has been revised against the firmware sources.** Every `file:line`
below was opened and read, not inferred. Where the first draft of this work order
was wrong about the firmware, the text now states the verified behaviour instead —
see in particular §1 *Output side*, where the originally proposed motor fix
recovered nothing and the servo claim was inaccurate. Appendix A records the
defects found on the way that are deliberately **not** being fixed, and Appendix B
is the complete audit of the old-domain constants that §1 must eliminate.

## Ground rules for all ten items

- **Still one file.** No build step, no npm, no CDN, no font, no network call, no
  telemetry. It must keep working from `file://` with the devtools console clean.
- **No second implementation.** Every block stays a single `def({...})` declaring
  `sim` and `emit` side by side. The new documentation tab (§9) must *derive* its
  content from `NODES` — if it contains one hand-written sentence about a block
  that is already in that block's `help`, it is wrong.
- **No float in the graph math.** There are currently exactly two float boundaries:
  the gamepad axis conversion (`PAD.padToStage0`, ~line 2560) and the illustrative
  robot integrator (`SIM.integrateRobot`, ~line 2459). §8 grows the second one — it
  must still terminate in `Math.round(...)` before any value reaches `SIM.gyro` /
  `SIM.accel`, and a self-test assertion must prove it.
- **The self-test is the contract.** `runSelfTest()` runs at boot, export stays
  blocked while it has not run or has a failure. Every item below that changes
  arithmetic must add assertions, not just avoid breaking the existing ones.
- **Keep the section banners.** New code goes inside the right `SECTION:`, or gets
  its own banner. Do not let the file turn into one blob.
- Tabs for indentation, English identifiers and UI text, comments explaining *why*
  and citing `file:line` of the firmware when they encode firmware behaviour.

## Phases and order of work

**Phase 1 — mandatory:** §1 → §3 → §4 → §5 → §6 → §2 → §7 → §9.
§1 first because it changes the model everything else is validated against; the
canvas interaction fixes (§3-§6) next because they are small and independent; the
two big UI features (§2, §7, §9) after them.

**Phase 2 — deferred:** §8, the live robot view and the IMU closed loop. It is
fully specified at the end of this document so that it does not need to be
redesigned when it is picked up, but it is not part of the phase 1 delivery.

Work in stages: stop after each § for a browser check before starting the next
one. One commit per §.

---

## §0 — Verification protocol

There is no browser in the implementation environment and there must be no test
runner in the repository, so verification happens through a **throwaway node
harness** built in the session scratchpad and never committed.

- Node 24 is available. The harness extracts the pure sections of the HTML
  (`FAC_MATH`, `RECEIVER`, `INTERVALS`, `NODE_CATALOG`, `GRAPH`, `VALIDATE`,
  `CODEGEN`, `SELFTEST`, `PRESETS`) by their `SECTION:` banners, evaluates them
  with minimal stubs for the handful of DOM symbols they touch, and calls
  `runSelfTest()` and `headlessMix()`.
- The harness lives in the scratchpad only. It is a verification aid for the
  implementer, not an artefact: `CLAUDE.md` says no test runner, and that stands.
- Every § below carries a **Done when** block. Those are the acceptance gates; a
  § is not finished until every line of its block has actually been executed, not
  reasoned about.
- The one thing the harness cannot cover is the pointer interaction of §2-§7.
  Those sections' gates are explicitly manual and must be checked in a browser by
  the user before the next § starts.

---

## §1 — Channel domain becomes symmetric: −1000 … +1000

### The problem, precisely

The channel domain is *inconsistent between producers and consumers*, and the
asymmetric mix input is the visible symptom of that.

| stage | file | domain produced/assumed |
|---|---|---|
| capture (PWM) | `fac_pwm_receiver.c:82-84` | `map_uint32(..., 0, RESOLUTION-1)` then clamp to `RESOLUTION-1` → **0…999** |
| capture (PPM) | `fac_ppm_receiver.c:62` | same → **0…999** |
| deadzone | `fac_std_receiver.c:86-127` | maps in from `0…RESOLUTION` and back out to `0…RESOLUTION` → **already written for 0…1000** |
| store | `fac_std_receiver.c:60-67` | clamps to `RESOLUTION-1` → **0…999** |
| mix input | `fac_mixes.c:111-115`, `fac_functions.c:79-83` | `FAC_math_from_range(rx, 0, RESOLUTION)` → **assumes 0…1000** |

Two of the three stages already speak `0…1000`. Only the capture and the store
use `RESOLUTION-1`. That mismatch is what makes a mix input reach `-1000` but
only `+998`.

### Chosen fix — widen the input domain to `0…1000`

Rationale, so it does not get re-litigated: `0…1000` is 1001 values and therefore
has an **exact centre** — `rx = 500` gives `from_range(500,0,1000) = 0` with no
rounding, and the documented identity `mix_input = 2*rx - 1000` holds exactly.
Narrowing the consumer to `0…999` instead would make the stick centre land on
`+1` with the deadzone off, because 1000 values have no exact middle.

**Firmware — input side:**

1. `Core/Src/FAC_Code/fac_std_receiver.c:60-67` — `FAC_std_receiver_SET_channel()`
   clamps to `RECEIVER_CHANNEL_RESOLUTION`, not `- 1`. Replace the `// -1 because
   number 0 is considered` comment with one that states the domain is `0…1000`,
   1001 values, centre 500.
2. `Core/Src/FAC_Code/fac_pwm_receiver.c:82-84` — map to `0, RECEIVER_CHANNEL_RESOLUTION`
   and clamp to `RECEIVER_CHANNEL_RESOLUTION`.
3. `Core/Src/FAC_Code/fac_ppm_receiver.c:62` — same map change. The clamp there is
   commented out already; leave it commented, `map_uint32` bounds the result.
4. **Do not touch the deadzone.** It is already correct for this domain. Two of its
   guards are unreachable dead code — see Appendix A — and they stay as they are.

### Output side — what the first draft got wrong

The first draft claimed the same off-by-one existed mirrored on the output side and
that "full positive travel is unreachable at *both* ends of the chain". That is
**not what the sources say**, and the two fixes it proposed are one unnecessary and
one actively harmful. The verified situation:

**Servo.** `fac_mapper.c:102` produces `FAC_math_to_range(v, 0, SERVO_POSITION_RESOLUTION)`,
i.e. `p = (v + 1000) / 2` over `0…1000`. `FAC_servo_SET_position()`
(`fac_servo.c:30-37`) clamps that to `MAX_SERVO_VALUE = 999`.

- The clamp is **load-bearing, not defensive**. The pulse is
  `p_us = span * position / MAX_SERVO_VALUE` (`fac_servo.c:98`), so a position of
  1000 would produce a pulse *beyond* the configured `max_us`.
  `docs/README_API.md:537` states this explicitly. Do not describe this clamp as
  defensive and do not remove it.
- Full travel is therefore **already reachable**: `v = 998` gives position 999,
  which is exactly `max_us`. The real defect is smaller and different — a
  three-value flat spot at the top, since `v = 998`, `999` and `1000` all land on
  position 999, and a map that is not uniform across the travel.

**Motor.** `fac_mapper.c:75-78` produces `speed = abs(v) * MOTOR_SPEED_RESOLUTION / FAC_VALUE_MAX`,
which is exactly `abs(v)` because both constants are 1000. `FAC_motor_SET_speed()`
(`fac_motors.c:63-68`) clamps it to `MAX_DMA_PWM_VALUE = PWM_STEPS - 1 = 999`
(`DMApwm.h:32`).

- The originally proposed `abs(v) * (MOTOR_SPEED_RESOLUTION - 1) / FAC_VALUE_MAX`
  yields **the same value at full scale** (1000 → 999, exactly as the clamp already
  did) and truncates everywhere below it (500 → 499). It costs the exactness that
  `fac_math.h:28` and `docs/README_MIX_EDITOR_API.md:96` describe as the reason the
  ±1000 scale was chosen, and buys nothing. **Rejected.**
- The actual ceiling is the clamp, and it is a conservative choice in
  `fac_motors.c`, not a hardware limit: `setSoftPWM()` (`DMApwm.c:73-76`) accepts
  `duty == PWM_STEPS` and its full-buffer loop `i < duty` then sets all
  `PWM_STEPS` entries, driving the pin high for the whole period — a true 100 %
  duty. The hardware has been confirmed safe at 100 %.

### Firmware — output side

5. `Core/Src/FAC_Code/fac_mapper.c:102` — servo position becomes
   `FAC_math_to_range(outputLinkedValue, 0, MAX_SERVO_VALUE)`. Write
   `MAX_SERVO_VALUE`, not `SERVO_POSITION_RESOLUTION - 1`: it is the same number
   and it ties the expression to the divisor in `fac_servo.c:98` that makes it
   correct. Comment the two consequences: the map becomes uniform and the top flat
   spot disappears; the centre `v = 0` now lands on position 499 instead of 500,
   which is half a step below mechanical centre — 0,05 % of travel, and unavoidable
   because a 1000-step device has no exact middle. The `FAC_servo_SET_position()`
   clamp stays, and its comment must say it bounds the pulse formula.
6. `Core/Src/FAC_Code/fac_mapper.c:75-78` — **unchanged**. Keep
   `abs(v) * MOTOR_SPEED_RESOLUTION / FAC_VALUE_MAX` and keep the
   `// exact, the two resolutions are equal` comment, which is true and is the
   point. Add one line saying the full-scale ceiling now lives in the clamp below.
7. `Core/Src/FAC_Code/fac_motors.c` — this is the real motor fix, and it is
   **two coupled edits that must land together**:
   - `:63-68` — `FAC_motor_SET_speed()` clamps to `MOTOR_SPEED_RESOLUTION`
     (identical to `PWM_STEPS`, `DMApwm.h:25` defines one as the other), so speed
     1000 survives.
   - `:96-103` — the brake-enabled branch drives the pin pair as
     `MAX_DMA_PWM_VALUE - speed` / `MAX_DMA_PWM_VALUE`. Both references become
     `PWM_STEPS`.

   > **Do not raise the clamp without this second edit.** With the clamp at 1000 and
   > the pair still at 999, `999 - 1000` underflows `uint16_t` to 65535, `setSoftPWM`
   > clamps that to `PWM_STEPS`, and the complementary pin goes fully high alongside
   > the always-on pin: a full-throttle command would brake the motor. With
   > `PWM_STEPS` on both, speed 1000 gives `pinB = 0` / `pinF = PWM_STEPS` (true
   > 100 %) and speed 0 gives both pins high, which is the brake state the comment
   > table at `:85-95` already documents.

   The coast branch (`:105-110`) needs no change — it writes `speed` and `0`
   directly and has no complement to underflow.
   Rewrite the `:85-95` comment block: the "use -1 on every duty … ALREADY
   CONSIDERED ON MAX_DMA_PWM_VALUE" reasoning is exactly what is being reversed.
8. `Core/Inc/Libraries/DMApwm.h` — **untouched**. `MAX_DMA_PWM_VALUE` is the
   library's own last-addressable-index notion and stays defined even though
   `fac_motors.c` no longer uses it; the library boundary is not ours to redraw.
   Note in the commit message that the macro now has no user outside the header.

### Firmware — documentation, in scope

The firmware docs state the old domain in ten places and are the sources of truth
the tool cites. If they stay at `0…999` the next agent rebuilds the asymmetry.

9. `docs/README_API.md` lines 148 (the chain diagram), 391
   (`FAC_std_receiver_GET_channel` return range), 448
   (`FAC_mixes_update_mix_inputs` normalisation), and 537 (servo pulse — restate
   full deflection with the new mapper expression).
10. `docs/README_MIX_EDITOR_API.md` lines 114 (the code snippet comment), 317, 511
    and 518 (the `0 … 999` return contract). Line 96's "conversions at both ends
    are exact" survives: the input side becomes exact and the motor side stays
    exact; only the servo now trades half a step for uniformity, and that has to be
    said there.
11. The firmware's own `CLAUDE.md` lines 41 (chain diagram) and 55 (the
    `[0, RECEIVER_CHANNEL_RESOLUTION-1]` clamp claim), and line 99 if the servo
    wording needs it.

### Firmware — check and report on, do not change blindly

- `fac_app.c:116-118` and `:160-162` arming compare against
  `RECEIVER_CHANNEL_RESOLUTION / 100 * threshold` — unaffected, confirm.
- `fac_settings.c:216` `% RECEIVER_CHANNEL_RESOLUTION` is inside
  `#ifdef IM_TESTING_FAC_TOOL`, a fake stick generator — harmless, mention it.
- USB telemetry ships the raw channel as `uint16`; the PC-side tool now sees a
  `0…1000` scale instead of `0…999`. Note it in the commit message.
- `FAC_motor_make_noise()` (`fac_motors.c:175`) sets speed 50 — unaffected.
- The surviving `RECEIVER_CHANNEL_RESOLUTION - 1` after this work must be exactly
  one: `MAX_SERVO_VALUE` in `fac_servo.h:15`, which is correct because the servo
  position really does have 1000 steps. Grep and justify any other survivor.

### Tool — `FAC_mix_editor.html`

12. Rewrite the `SECTION: RECEIVER` header comment (~line 410). The four-stage
    table becomes `0: 0…1000`, `1a: 0…1000`, `1b: clamp to RESOLUTION (now a no-op
    in practice)`, `2: -1000…+1000`. Keep the stages separate — the reason they
    exist has not changed. Cite the firmware `file:line` for each stage as it does
    today, and record that the asymmetry was a firmware bug that has been fixed,
    with the commit reference. The paragraph currently headed "Stage 1b is the one
    the mix editor brief got wrong" is now historical and must be rewritten, not
    deleted: it explains why the stages are modelled separately at all.
13. `rxStoreClamp()` (~line 465) clamps to `RECEIVER_CHANNEL_RESOLUTION`.
14. Kill every hard-coded remnant of the old domain. **Appendix B is the complete
    list** — the first draft of this work order named five sites and there are
    seventeen. Work through the appendix, then re-grep `998`, `999` and
    `RECEIVER_CHANNEL_RESOLUTION - 1` and account for every remaining hit.
15. Model the output side too: wherever the tool converts a mix output to a device
    value for display (`SIM.deviceValue` consumers, `drawRobot`, the Robot tab
    readouts), mirror the mapper exactly — servo `m_to_range(v, 0, MAX_SERVO_VALUE)`
    → `0…999`, motor `abs(v)` → `0…1000` with the sign carried as direction. Add
    the two constants next to `RECEIVER_CHANNEL_RESOLUTION` at line 275 with their
    `config.h` / `fac_servo.h` provenance.

### Tool — self-test additions, all in `SECTION: SELFTEST`

16. New assertions:
    - `rxStage1(1000, 0, 1) === 1000` and `rxStage2(1000, false) === 1000` — full
      positive travel is now reachable.
    - `rxStage2(0, false) === -1000`, `rxStage2(500, false) === 0` — exact centre.
    - `rxStage2(rx, false) === 2*rx - 1000` for every `rx` in `0…1000`. Note that
      line 2748 already proves this identity for `m_from_range`; what is new is
      that the *chain* now preserves it, because stage 1b no longer truncates it.
    - the full deadzone sweep (line 2753) re-baselined to `0…1000`, and extended:
      for every percentage 0…20 and every channel 1…8 the result stays inside
      `0…1000`, is an integer, and is monotonic non-decreasing in the input.
    - the gamepad boundary: `PAD.padToStage0(defaults()[0], 1) === 1000`, `-1` gives
      `0`, `0` gives `500`, and the result is always an integer in `0…1000`
      (line 2829's range check moves with it).
    - servo and motor mapper mirrors: `m_to_range(1000, 0, MAX_SERVO_VALUE) === 999`,
      `m_to_range(-1000, 0, MAX_SERVO_VALUE) === 0`, `m_to_range(0, 0, MAX_SERVO_VALUE) === 499`,
      and the motor path is the identity on `abs(v)` over the whole normalized range.
    - the `simple_tank` parity grid (line 2840) gets `1000` added to its sample set
      and keeps `998` (still a legal value, just no longer the maximum).

### Tool — documentation

17. Update this folder's `CLAUDE.md`: the "channel chain" section, the `+998` claim
    in the *Precedence* paragraph, and the statement that the brief's `0…1000` was
    wrong — the brief was describing the intent, the source has now caught up with
    it. Add the output-side row: servo `0…999` via `MAX_SERVO_VALUE`, motor
    `0…1000` with a true 100 % duty.
18. No version-skew warning ships in the tool. A new tool on old firmware simulates
    `+1000` where the hardware gives `+998`; that belongs in the firmware changelog
    and the release notes, not in the editor UI and certainly not in the generated
    `.c`, which must stay byte-identical.

**Done when:**

- [ ] harness: `runSelfTest()` green, including every assertion in item 16
- [ ] harness: `headlessMix()` on `simple_tank` matches the hand transcription over
      the grid extended with `1000`
- [ ] harness: the generated `.c` and `.h` for every preset are byte-identical to
      the pre-§1 output — §1 changes no emitted code
- [ ] `grep -n "998\|999" FAC_mix_editor.html` returns only hits justified in
      Appendix B as intentional survivors
- [ ] `grep -rn "RECEIVER_CHANNEL_RESOLUTION *- *1" Core/` in the firmware returns
      only `fac_servo.h:15`
- [ ] browser: a stick slider at maximum shows `+1000` on every mix input, and the
      Sim & sticks readout agrees with the harness

---

## §2 — Resizable GUI and global UI scale

The four splitters already exist in the markup and CSS — `#splitPalette` (line
205), `#splitRight` (219), `#splitInsp` (224), `#splitBottom` (231), styled by
`.vsplit` / `.hsplit` (lines 61-66) — **and no JavaScript ever moves them.** They
are decoration.

Required:

- Wire all four. Pointer capture on `pointerdown`, `body.resizing-v` /
  `resizing-h` classes while dragging (the CSS is already there), min and max
  sizes per pane so nothing can be dragged to zero or push the canvas out of
  existence. Double click on a splitter resets that pane to its default.
- A collapse toggle on the palette, the right column and the bottom panel — the
  bottom one already has `#btBottomToggle`, make the other two match.
- **Global UI scale**: a control in the top bar, 70 %…150 %, driving a
  `--ui-scale` custom property.
  - It applies to **the chrome only**: top bar, palette, inspector, right column,
    bottom panel, their font sizes and paddings.
  - It does **not** apply to the nodes on the canvas. Node metrics and port hit
    areas stay fixed in world coordinates, and `P.view.z` remains the only thing
    that changes their apparent size. This is deliberate: nodes that grow in world
    coordinates would make a saved `x`/`y` layout occupy different space at
    different scales and would turn the §5 grid into a relative unit.
  - It must not touch `P.view.z`. Canvas zoom and UI scale are different things and
    must stay independent.
  - Add a compact/normal density switch if it falls out for free.
- **Persistence in `localStorage`, not in the project file.** Key
  `facmix.layout.v1`. Panel sizes are a property of the person, not of the mix; a
  `.facmix.json` handed to someone else must not resize their editor. Do not bump
  `SCHEMA_VERSION` for this. `localStorage` already holds the autosaved project
  under `AUTOSAVE_KEY` (line 4298) — the layout key is separate and the autosave
  restore path must not read or write it.
- The key also carries the §5 grid size and, in phase 2, the §8 overlay state.
- A *Reset layout* entry that clears the key and restores the defaults.

**Done when:**

- [ ] browser: every pane resizes, double click resets it, and all four survive a
      reload
- [ ] browser: the canvas is usable at 70 % and at 150 %, and node size on screen
      is unchanged by the scale control
- [ ] browser: export a `.facmix.json` and confirm no layout key is inside it
- [ ] browser: *Reset layout* restores the defaults without touching the project

---

## §3 — Dragging a collapsed group is not visible until release

**Cause, confirmed.** In the `mousemove` handler, the `move` branch (line ~3454)
updates the DOM with `$('#nodes .node[data-id="' + id + '"]')`. The members of a
collapsed group are not rendered — `renderNodes()` skips them via `isHidden(n)`
and draws one box carrying `data-grp` instead. So the selector matches nothing,
nothing moves on screen, and the jump only happens on the `refreshAll()` at
mouseup. The mousedown handler for a group box (line ~3413) also calls
`refreshAll()`, a full re-render, before the drag even starts.

Required:

- On mousedown, resolve the elements to move **once** into `dragState.doms` —
  node elements *and* the collapsed group boxes whose members are in the
  selection, each with its starting `x`/`y`. Per-frame `querySelector` goes away.
- The group box moves with its members and stays in sync with the box origin
  (`min(x)`, `min(y)` of the members).
- Coalesce the visual update into one `requestAnimationFrame`; `renderWires()`
  runs at most once per frame. Multi-selection drags of thirty nodes must stay
  smooth.
- Drop the `refreshAll()` from both mousedown paths — toggle the `sel` class
  directly and refresh the inspector, do not re-render the whole graph to start
  a drag.

**Done when:**

- [ ] browser: dragging a collapsed group tracks the cursor continuously, with the
      wires following, and the box lands where the cursor released it
- [ ] browser: a 20-node selection drags without stutter
- [ ] browser: expanding the group afterwards shows the members at the offsets they
      had before the drag
- [ ] harness: `simple_tank` still exports byte-identically — grouping is visual only

---

## §4 — Marquee selection does not stick

**Cause, confirmed.** The marquee itself works. The `click` listener on
`#viewport` (line ~3504) fires *after* the `mouseup` that completed the marquee,
sees `e.target` as `#viewport` or `#world`, and wipes the selection it just
built. Release the drag over a node or a wire and the target is different, so the
selection survives — exactly the reported symptom.

Required:

- Remove that `click` listener. Clearing the selection on an empty-canvas click is
  already handled by the mousedown path (line ~3443); if a guard is still wanted,
  gate it on a `moved` flag set by `mousemove`, with a few pixels of dead zone so
  a shaky click still counts as a click.
- **Intersection test**, as today — a block enters the selection if the marquee
  touches it at all, not only when it is fully contained.
- **Live feedback**: blocks that would be selected get the highlight *while* the
  marquee is being dragged, not on release. Use a lightweight class toggle, not a
  re-render.
- Include collapsed group boxes in the hit test — selecting a box selects its
  members, matching the existing click behaviour.
- Make sure `NODE_GEOM` is populated for every visible node and group box before
  the first marquee; the current `{w:120,h:60}` fallback silently misjudges wide
  nodes.
- Shift keeps its current meaning (add / toggle). Wires stay non-selectable.

**Done when:**

- [ ] browser: drag a marquee over empty canvas across several blocks and release
      over empty canvas — the blocks stay selected and the inspector shows the count
- [ ] browser: the highlight appears during the drag, not on release
- [ ] browser: a marquee over a collapsed group box selects its members
- [ ] browser: shift-marquee adds to an existing selection

---

## §5 — Grid snap is unreliable

Three separate causes, fix all three:

1. **The multi-node drag snaps each node's absolute position independently**
   (line ~3453: `n.x = Math.round((s.x + dx) / grid) * grid`). Nodes whose
   starting coordinates are not multiples of the grid drift *relative to each
   other* during the drag. Snap the **delta** instead: compute it from the node
   under the cursor, so that node lands exactly on the grid and every other node
   in the selection moves by the same amount, preserving the internal spacing
   exactly.
2. **The modifier state goes stale.** The snap bypass reads `keyState.ctrl`
   (line ~3450), which is only refreshed by `keydown` / `keyup` on `window`
   (lines 4304-4320) — and the `keydown` handler returns early when the focus is in
   an input, so the state is not even updated consistently. Press Ctrl+C, alt-tab,
   come back, and it can stay `true` — snap silently off. Read `e.ctrlKey` from the
   live mouse event instead, and add a `blur` handler on `window` that resets
   `keyState` regardless.
3. **Only the drag path snaps at all.** Palette drop (`addNode(t, w.x-50, w.y-20)`),
   double-click insert, paste (`pasteSel`, `c.x += 30`) and the §7 auto-layout all
   produce unsnapped coordinates, so the grid looks like it works sometimes.
   Introduce one `snapPos(x, y)` helper and route every position-producing path
   through it.

Also:

- Grid size becomes a user choice — off / 5 / 10 / 20 / 25 — in the top bar,
  persisted with the layout (§2), default 10 to match today.
- Draw the grid as a CSS background on `#viewport` aligned to `P.view` and the
  chosen size, so snapping is *visible*. It must not intercept pointer events.
- Arrow keys nudge the selection by one grid step, Shift+arrow by five. With the
  grid off, one step is 1 px. The nudge goes through `snapPos()` too, and shares
  one `pushUndo()` per burst rather than one per key repeat.

**Done when:**

- [ ] browser: with snap at 10, a block created by each of palette drop, double
      click, paste and auto-layout sits on a multiple of 10
- [ ] browser: a multi-selection drag preserves the relative offsets exactly —
      check two nodes that started 37 px apart
- [ ] browser: Ctrl+C, alt-tab away and back, then drag — it still snaps
- [ ] browser: the drawn grid stays aligned to the blocks while panning and zooming
- [ ] browser: the grid size choice survives a reload

---

## §6 — Right button drag pans

- `mousedown` with `e.button === 2` starts the same `pan` drag state that middle
  button, Alt and Space already start (line ~3437).
- Suppress the browser context menu on `#viewport` (and only there) with
  `preventDefault()`.
- **No context menu of our own** — a stationary right click does nothing.
- The right-button `mouseup` must not clear the selection or start a marquee.
- Update `#editHint` (line 215) and the shortcut table in the help modal
  (line ~4253) to list the right button.
- While the keyboard handler is open: `F` (line 4316) fires on any modifier
  combination, so `Ctrl+F` frames the graph instead of opening the browser's find.
  Gate it on no modifier being held. §7 adds `L` next to it and must be gated the
  same way from the start.

**Done when:**

- [ ] browser: right-button drag pans, and releasing does not disturb the selection
- [ ] browser: a stationary right click on the canvas opens nothing
- [ ] browser: the context menu still works everywhere outside `#viewport`
- [ ] browser: `Ctrl+F` no longer frames the graph; bare `F` still does

---

## §7 — Auto-layout button

A button next to *Frame* in the top bar, shortcut `L` (verified free — the only
current bindings are Delete/Backspace, Ctrl+Z/Y/C/V/A and bare `F`), that arranges
the graph left to right by topological rank.

- Reuse `topoOrder()`. Rank = longest path from the sources, so every block sits
  strictly to the right of everything feeding it. Sinks (mix outputs) are pinned
  to the last column.
- Order within a column by the barycentre of the predecessors' rows, two or three
  sweeps forward and back — enough to remove most crossings without importing a
  layout library.
- Column width from the measured node widths in that column plus a gutter, row
  spacing from the measured heights. Positions go through `snapPos()` (§5).
- A **collapsed group is laid out as a single unit** at its box size, and its
  members are repositioned to keep their relative arrangement inside that
  footprint, so expanding it afterwards does not produce a pile.
- Nodes that no edge reaches — orphans and freshly dropped blocks — go into a
  trailing column of their own rather than being scattered through rank 0.
- One `pushUndo()` for the whole operation, then frame all.
- Cyclic graphs (legal when a cycle passes through a stateful block) must not
  hang the ranking — break cycles at the stateful node, the same one that makes
  them legal.

**Done when:**

- [ ] browser: the `simple_tank` preset laid out automatically is readable with no
      overlapping blocks
- [ ] browser: Ctrl+Z restores the previous positions in one step
- [ ] browser: a preset containing a stateful cycle lays out without hanging
- [ ] browser: a collapsed group survives the layout and expands without a pile
- [ ] harness: the exported `.c` is byte-identical before and after a layout —
      positions are not semantics

---

## §9 — Block documentation section

A new bottom tab, *Blocks*, between *Generated code* and *Registration*,
**generated entirely from `NODES`**.

Per block, all derived, none re-typed:

- label, catalogue id, category, whether it is advanced
- input ports with their kinds, output kind
- parameters with type, range and default
- division count (`divs` / `divsOf`) and the sqrt step note where it applies
- the proven output interval from `range()`
- the `help` string, which already states the division count and the range
  constraint
- **the real emitted C**, obtained by calling the block's own `emit()` with
  placeholder arguments. Use a throwaway context — it must not touch the real
  `makeCtx()` state, must not register statics or resets, and must fall back to a
  short note if a block's `emit` needs context it cannot get. This is what
  guarantees the documentation cannot drift from the generator.

Around it:

- search and category filter, mirroring the palette
- a header section covering the receiver chain (§1, in its post-fix form), the
  group-1 versus group-2 versus group-4 clamp and overflow semantics, and the cost
  model — **moved** out of the help modal, not duplicated into it
- the help modal keeps the keyboard shortcuts and the workflow, loses the theory,
  and gains a link that opens the *Blocks* tab. One copy of each explanation
- a link from the inspector and from the palette entry to that block's card
- a *copy* button per card

**Done when:**

- [ ] harness: every id in `NODES` produces a card, and the count matches
      `Object.keys(NODES).length`
- [ ] harness: adding a throwaway `def({...})` makes a card appear with no other edit
- [ ] harness: the C shown for each block used by `simple_tank` appears verbatim in
      the generator's output for that preset
- [ ] harness: building every card does not mutate the real generator state —
      export before and after and compare
- [ ] browser: the help modal no longer contains the receiver table or the group
      semantics, and its link opens the tab

---

## §8 — Live 2D robot view, closed loop with the IMU — **PHASE 2**

Deferred out of the phase 1 delivery. Specified in full so it does not need to be
redesigned when it is picked up.

Today `drawRobot()` returns early when the Robot tab is hidden (line ~3931) and
`integrateRobot()` is a fixed 120 px/s differential drive hard-wired to
`P.sim.mapper.M1` / `M2` (line ~2459).

### Placement

- A **floating overlay** anchored bottom-right inside `#editor`: always visible,
  independent of which bottom tab is open. Draggable by its header, resizable
  from a corner, collapsible to a title bar, with an opacity control so it never
  hides the graph permanently.
- A **dock button** that moves it into the right column or into the Robot tab and
  back. Position, size, dock state and opacity persist with the layout (§2), in
  `facmix.layout.v1` — they are a property of the person, not of the mix.
- Split rendering from the tab check so the overlay draws whenever the simulator
  runs, and the Robot tab reuses the same renderer rather than a copy.

### Drive sources and kinematics preset

The current hard-wiring to M1/M2 is false for any robot that does not happen to
use those two outputs for traction — a weapon on M1 makes the view nonsense.

- Two selectors, *left wheel* and *right wheel*, choosing any mapped device
  (`M1…M4`, `S1…S2`), defaulting to `M1` and `M2`.
- A kinematics preset next to them: **2-wheel differential** (default) or
  **4-motor skid-steer**, where the selectors become left pair and right pair
  (`M1+M3` / `M2+M4` by default) and each side's speed is the average of its pair.
- Both live in `P.sim`, alongside the physical units below.

### Physical units

Replace the arbitrary constants with values the user sets, stored in `P.sim`
(these describe the robot being built, so they *do* belong to the project — bump
`SCHEMA_VERSION` to 2 and default them for older files on load):

- robot length and width, cm
- track width, cm
- maximum linear speed at full stick, cm/s
- derived and displayed, not entered: maximum yaw rate = `maxSpeed / trackWidth`
  in °/s, so the model stays self-consistent

Kinematics: `vL`, `vR` in cm/s from the mapper values for the selected sides scaled
by the maximum speed; `v = (vL+vR)/2`; `ω = (vR-vL)/trackWidth`. Integrate at the
existing 1 ms step. The view scale is cm per pixel, auto-fit with a manual
override, plus a follow/centre toggle and a fading trail of past positions.

### Closed loop: the robot drives the IMU

Add a selector *IMU source: simulated robot / manual sliders*, **defaulting to
the simulated robot**. When it is on the robot:

- gyro Z from `ω`, converted to mdps and then to raw counts at 70 mdps/count
  (`LSM6DS3_GYRO_SENSITIVITY_MDPS`, `LSM6DS3.h:130`, ±2000 dps full scale)
- gyro X, Y from the (zero) roll and pitch rates, unless a tilt model is added
- accel X from `dv/dt` (longitudinal), accel Y from `v·ω` (centripetal), both in
  mg then raw at 0.488 mg/count (`LSM6DS3_ACCEL_SENSITIVITY_UG`, `LSM6DS3.h:129`,
  ±16 g full scale)
- accel Z holds gravity, 1000 mg
- optional noise amplitude, off by default
- everything clamped to `int16` and **rounded to an integer before it is written
  to `SIM.gyro` / `SIM.accel`** — this is the float boundary rule, and it needs a
  self-test assertion proving no non-integer ever reaches those arrays

When the selector is on *manual*, the sensor sliders behave exactly as they do
today. Document in the panel which mounting convention the axes assume, and cite
the firmware file that fixes it.

### What is drawn (this covers item 10)

On top of the existing chassis, motor bars and servo horns:

- the **heading** as an arrow from the robot centre
- the **body-fixed axis triad**: X forward, Y left, Z out of the plane drawn as a
  circle with a rotation arc whose length and direction track `ω`, each axis
  colour-coded with a legend
- the **acceleration vector** as a second arrow, distinguishable from heading
- a small **world axis indicator** in a corner, so body versus world frame is
  never ambiguous
- numeric readouts: speed cm/s, yaw rate °/s, and the raw gyro/accel counts the
  graph is actually reading
- reset pose, pause, and clear trail

Keep the existing "illustrative, not a physical model" caveat visible — it is a
kinematic sketch, not a dynamics simulation, and the panel must say so.

**Done when:**

- [ ] harness: a scripted run of the simulator with the robot IMU source active
      asserts `Number.isInteger` on every value ever written to `SIM.gyro` and
      `SIM.accel`, over a sweep of stick inputs including both extremes
- [ ] harness: a `.facmix.json` saved at `SCHEMA_VERSION` 1 loads with the new
      `P.sim` fields defaulted, and re-saves at 2
- [ ] harness: with the IMU source on manual, the sensor path is bit-identical to
      the pre-§8 behaviour
- [ ] browser: the overlay draws with any bottom tab open, docks and undocks, and
      its geometry survives a reload
- [ ] browser: a preset using an IMU block responds to the simulated robot's yaw

---

## Appendix A — known, deliberately not fixed

Found while verifying this work order. Neither changes observable behaviour, and
fixing either is out of scope.

1. **`fac_std_receiver.c:98-101`, two unreachable guards in the deadzone.**
   `if (value > maxValue) temp = maxValue;` tests the raw `uint16_t` argument
   against `maxValue`, not the already-remapped `temp`, and after §1 the argument
   can never exceed `RECEIVER_CHANNEL_RESOLUTION` anyway; `if (value < minValue)`
   can never be true at all, since `value` is unsigned and `minValue` is negative.
   §1 item 4 says do not touch the deadzone and that stands — it is arithmetically
   correct for the new domain and every change there is a change to feel. Leave
   both, and leave the tool's port mirroring them line for line.
2. **`FAC_mix_editor.html:4316`, `F` ignores modifiers.** `if (e.key === 'f' || e.key === 'F') frameAll();`
   has no modifier guard, so `Ctrl+F` frames the graph instead of opening the
   browser's find. This one *is* picked up, but by §6 rather than as its own item,
   because §6 already opens that handler.

Also worth recording, since it looks like a bug and is not: channel 3 takes a
different arithmetic path through the deadzone (`fac_std_receiver.c:94`, `:120`) —
it is never remapped into ±RESOLUTION, so the centre-deadzone branch acts on the
raw `0…1000` throttle and effectively becomes a bottom-extremes deadzone. That is
intentional: throttle has no return spring. The tool's port must keep mirroring it.

---

## Appendix B — the old-domain audit

The complete list of sites that encode `0…999`. §1 item 14 must account for every
one of them. The first draft of this work order named five; there are seventeen in
the tool and ten in the firmware docs.

### Tool — `FAC_mix_editor.html`

| line | what |
|---|---|
| 415-425 | `SECTION: RECEIVER` header table and the "brief got wrong" paragraph |
| 465 | `rxStoreClamp()`, `RECEIVER_CHANNEL_RESOLUTION - 1` twice |
| 516-518 | `INTERVALS` header comment, "the real chain only reaches [-1000, +998]" |
| 583 | `rx_channel` `range: () => IV.mk(-1000, 998)` |
| 2499, 2559 | `SECTION: GAMEPAD` header comments, "stage-0 values 0..999" |
| 2569-2570 | `PAD.padToStage0`, `(RECEIVER_CHANNEL_RESOLUTION - 1)` in the conversion and in the clamp |
| 2745 | `T('from_range(999,0,1000)', …, 998)` — still true, but no longer the top of travel |
| 2753-2758 | deadzone sweep asserting the result is inside `[0, 999]` |
| 2763-2782 | eight `rxStage1` / `rxStage2` assertions built on 999 and 998 |
| 2782-2783 | `'mix input at the top of travel is +998, NOT +1000'` — inverts |
| 2829 | gamepad range check, `v > RECEIVER_CHANNEL_RESOLUTION - 1` |
| 2834 | `'a pad axis at +1 becomes stage 0 = 999'` |
| 2840 | `simple_tank` parity grid sample set |
| 3743, 3747 | Sim & sticks: the `stage 0 (0..999)` label and the sliders' `max="999"` |
| 3755-3756 | Sim & sticks explanatory paragraph |
| 4038 | gamepad tab explanatory paragraph |
| 4227-4232 | help modal channel-chain table and the paragraph under it |

Intentional survivors after the work: none. Every `998`/`999` in the file should be
gone or restated; if one remains, it must carry a comment saying why.

### Firmware documentation

| file:line | what |
|---|---|
| `docs/README_API.md:148` | chain diagram, `channels[8], integers 0 … 999` |
| `docs/README_API.md:391` | `FAC_std_receiver_GET_channel` return contract |
| `docs/README_API.md:448` | `FAC_mixes_update_mix_inputs`, `0…999` → `-1000…+1000` |
| `docs/README_API.md:537` | servo pulse paragraph — restate against the new mapper expression |
| `docs/README_MIX_EDITOR_API.md:96` | "conversions at both ends are exact" — qualify for the servo |
| `docs/README_MIX_EDITOR_API.md:114` | snippet comment, `0 .. 999` |
| `docs/README_MIX_EDITOR_API.md:317` | `FAC_mixes_update_mix_inputs` row |
| `docs/README_MIX_EDITOR_API.md:511` | `/* 1-BASED, returns 0 .. 999 */` |
| `docs/README_MIX_EDITOR_API.md:518` | "the returned value is `0 … 999`" |
| firmware `CLAUDE.md:41`, `:55`, `:99` | chain diagram, the clamp claim, the servo paragraph |

---

## Global regression checklist

Before calling any of this done:

- [ ] boot self-test green, and it still blocks export when red
- [ ] `simple_tank` still matches `fac_simple_tank_mix.c` over the parity grid
- [ ] every preset loads, simulates and exports
- [ ] the generated `.c` / `.h` for an unchanged graph is byte-identical to before
      this work — including after §1, which changes no emitted code
- [ ] round-trip: export a `.c`, re-import it, get the same graph
- [ ] `file://` open, console clean, no network request in the network tab
- [ ] no `float` and no `Math.floor` anywhere in the graph math; the only
      `Math.round` calls are the two documented float boundaries
- [ ] this folder's `CLAUDE.md` updated for §1 and for the new UI affordances
- [ ] the node harness deleted from the scratchpad, nothing test-shaped committed
- [ ] firmware changes left in the submodule working tree, uncommitted, for review

## Suggested commit messages

The firmware changes are **not** committed by the implementer — they are left in
the submodule working tree for review. These are the messages to use when they are
committed by hand.

**Firmware, one commit:**

```
receiver/mapper: make the value chain reach full scale at both ends

The channel domain was inconsistent between producers and consumers: the
deadzone and FAC_math_from_range already spoke 0..RECEIVER_CHANNEL_RESOLUTION
while the capture and the store clamped to RESOLUTION-1, so a mix input reached
-1000 but only +998. Widen the input side to 0..1000: 1001 values, exact centre
500, and the identity mix_input = 2*rx - 1000 now holds exactly.

  fac_std_receiver.c  SET_channel clamps to RESOLUTION, not RESOLUTION-1
  fac_pwm_receiver.c  map and clamp to RESOLUTION
  fac_ppm_receiver.c  map to RESOLUTION
  fac_std_receiver.c  deadzone untouched, it was already written for this domain

On the output side the servo mapper now targets MAX_SERVO_VALUE, so the map is
uniform over the travel instead of flattening the top three input values onto
position 999. The centre lands on 499 rather than 500, half a step below
mechanical centre, which is unavoidable for a 1000-step device. The clamp in
FAC_servo_SET_position stays: it bounds the pulse formula at fac_servo.c:98 and
is load-bearing, not defensive.

The motor scale is left exact - abs(v) * MOTOR_SPEED_RESOLUTION / FAC_VALUE_MAX
is the identity and multiplying by RESOLUTION-1 instead would have truncated the
whole scale to recover a ceiling the clamp already imposed. The ceiling is lifted
in fac_motors.c instead: SET_speed clamps to MOTOR_SPEED_RESOLUTION and the
brake-mode pin pair references PWM_STEPS. Both edits are required together -
with the clamp raised and the pair left at MAX_DMA_PWM_VALUE, PWM_STEPS-1-speed
underflows uint16 at full throttle and brakes the motor. setSoftPWM already
accepts duty == PWM_STEPS and drives the pin high for the whole period, so full
throttle is now a true 100% duty. MAX_DMA_PWM_VALUE stays defined in DMApwm.h
and now has no user outside that header.

Audit of RECEIVER_CHANNEL_RESOLUTION - 1: the only survivor is MAX_SERVO_VALUE
in fac_servo.h, which is correct - the servo position really does have 1000
steps. fac_app.c arming thresholds are percentage-based and unaffected.
fac_settings.c:216 is a fake stick generator behind IM_TESTING_FAC_TOOL.

USB telemetry ships the raw channel as uint16: the PC-side tool now sees a
0..1000 scale instead of 0..999.

Docs updated to match: README_API.md, README_MIX_EDITOR_API.md, CLAUDE.md.
```

**Tool, one commit per §.** For §1:

```
mix editor: channel domain becomes symmetric, -1000 .. +1000

Mirrors the firmware fix. The store clamp is now a no-op in practice, so a mix
input reaches +1000 and the stick centre is exact. The four stages stay modelled
separately - collapsing them would either double-apply the deadzone or invent
travel the hardware does not have.

Self-test: full positive travel, exact centre, the 2*rx-1000 identity across the
whole chain, the deadzone sweep re-baselined to 0..1000, the gamepad boundary,
the two mapper mirrors, and 1000 added to the simple_tank parity grid.

No generated code changes.
```

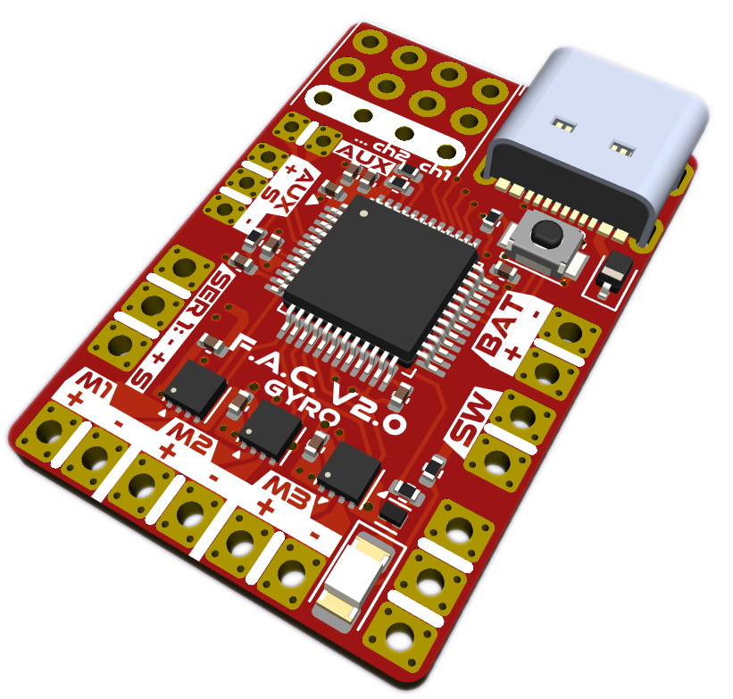
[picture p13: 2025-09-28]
TOOLS/FAC-Tool-for-FAC-V2.x/Illustration/images/FAC V2 F.png

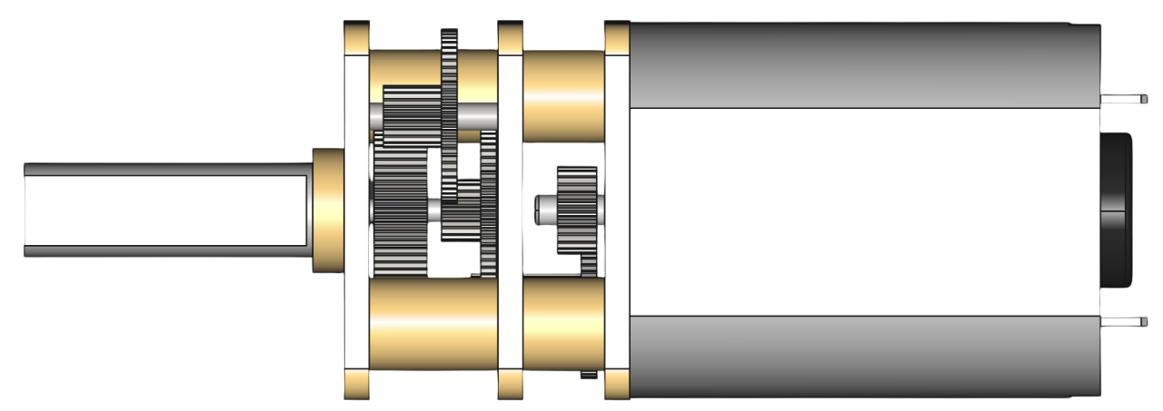
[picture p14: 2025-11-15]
TOOLS/FAC-Tool-for-FAC-V2.x/Illustration/images/N20.png

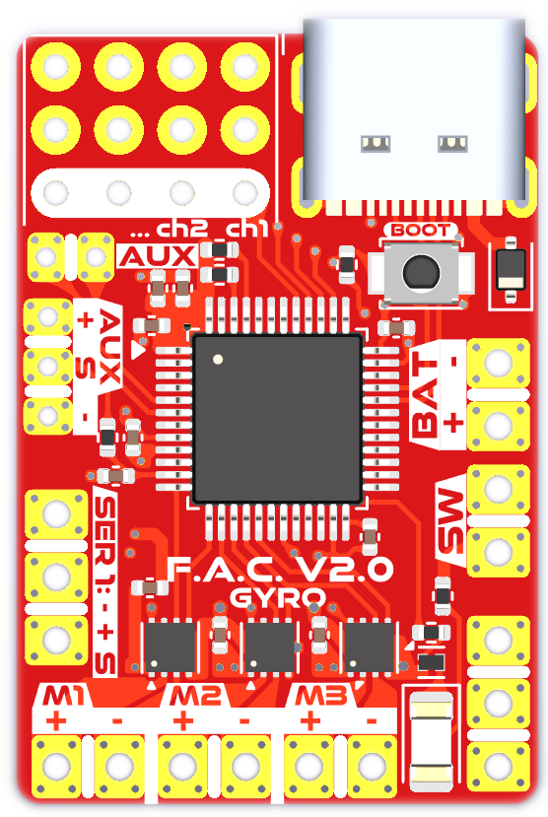
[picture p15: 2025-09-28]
TOOLS/FAC-Tool-for-FAC-V2.x/Illustration/images/FAC-V2-top-no-background.png

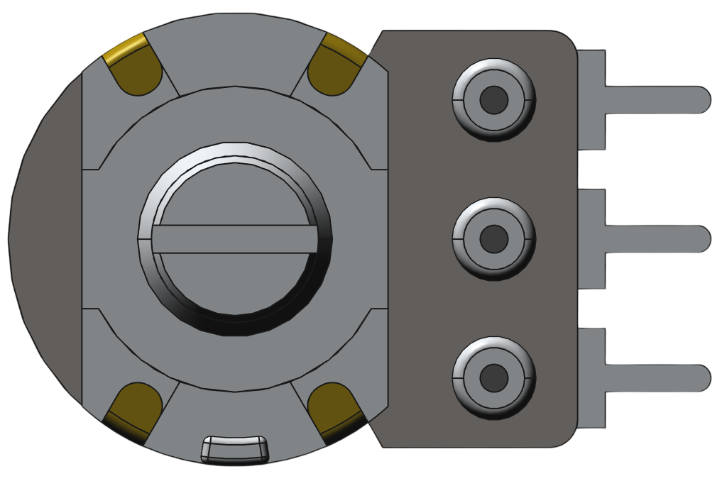
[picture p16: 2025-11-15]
TOOLS/FAC-Tool-for-FAC-V2.x/Illustration/images/potentiometer.png

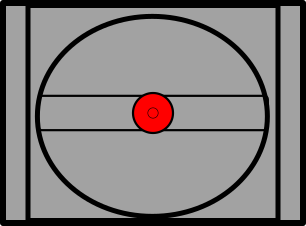
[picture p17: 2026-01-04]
docs/illustrations/stick centrale.png

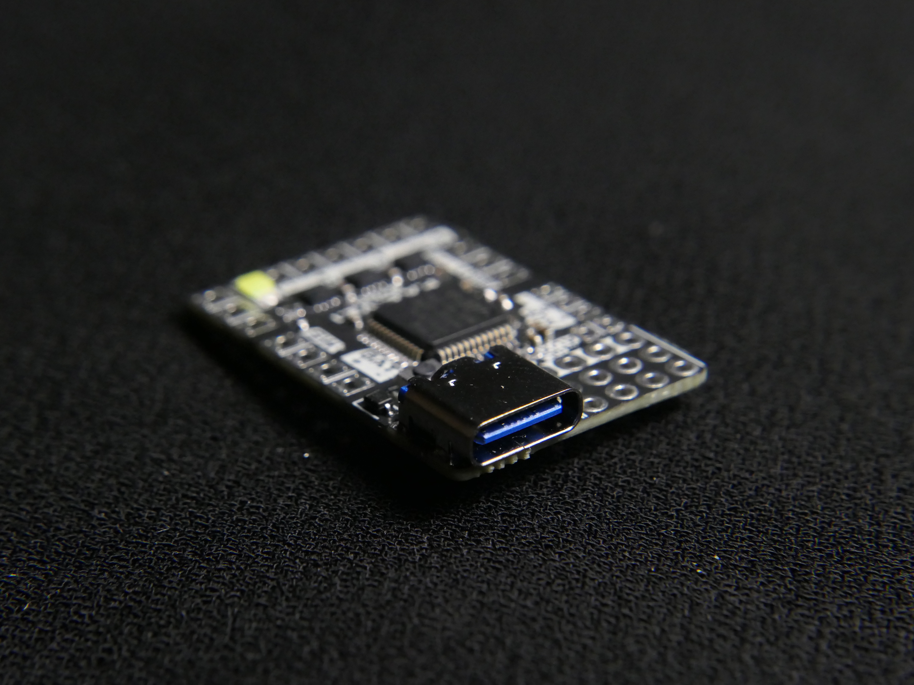
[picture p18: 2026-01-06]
images/real 5.jpg

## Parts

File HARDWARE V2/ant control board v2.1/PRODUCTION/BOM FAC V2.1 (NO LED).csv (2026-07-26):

Reference | Value | Part Name | Manufacturer | LCSC | Footprint | Qty
U8 | AT24C02C | AT24C02CM5/TR | HGSEMI(华冠) | C7432363 | Package_TO_SOT_SMD:SOT-23-5 | 1
J3 | USB-C_304A-ACP16X | TYPEC-304A-ACP16L | XUNPU(讯普) | C2909609 | _MIA footprint:USB_C_304A-ACP16X | 1
SW1 | BOOT | TS-3025-B-A-B | XKB Connection(中国星坤) | C2885149 | Button_Switch_SMD:SW_SPST_B3U-1000P | 1
Q1 | PNM3FD20V1E | PNM3FD20V1E | Prisemi(芯导) | C2875806 | Package_DFN_QFN:Diodes_DFN1006-3 | 1
C2-C3-C4-C5-C6-C7-C8-C13 | 4.70u | GRM155R61E475ME15D | muRata(村田) | C2858031 | Capacitor_SMD:C_0402_1005Metric | 8
U1 | GM7333 | GM7333TB | GATEMODE(捷茂微) | C2833582 | Package_TO_SOT_SMD:SOT-89-3 | 1
U5 | LSM6DS3 | LSM6DS3TR-C | ST(意法半导体) | C967633 | Package_LGA:LGA-14_3x2.5mm_P0.5mm_LayoutBorder3x4y | 1
D1 | 1N5819WS | 1N5819WS | Hottech(合科泰) | C191023 | Diode_SMD:D_SOD-323 | 1
R11 | 220 | RC0402FR-07220RL | YAGEO(国巨) | C112291 | Resistor_SMD:R_0402_1005Metric | 1
U6 | STM32F072CBTx | STM32F072CBT6 | ST(意法半导体) | C81720 | Package_QFP:LQFP-48_7x7mm_P0.5mm | 1
R3-R5 | 10.0k | RC0402FR-0710KL | YAGEO(国巨) | C60490 | Resistor_SMD:R_0402_1005Metric | 2
U2-U3-U4 | DRV8837 | DRV8837DSGR | TI(德州仪器) | C39159 | Package_SON:WSON-8-1EP_2x2mm_P0.5mm_EP0.9x1.6mm | 3
R1-R2-R6-R7-R8-R9-R10 | 5.10k | 0402WGF5101TCE | UNI-ROYAL(厚声) | C25905 | Resistor_SMD:R_0402_1005Metric | 7
R4 | 1.50k | 0402WGF1501TCE | UNI-ROYAL(厚声) | C25867 | Resistor_SMD:R_0402_1005Metric | 1
C9-C10-C11-C14-C15-C16-C17-C18-C19 | 100.0n | CL05B104KO5NNNC | SAMSUNG(三星) | C1525 | Capacitor_SMD:C_0402_1005Metric | 9

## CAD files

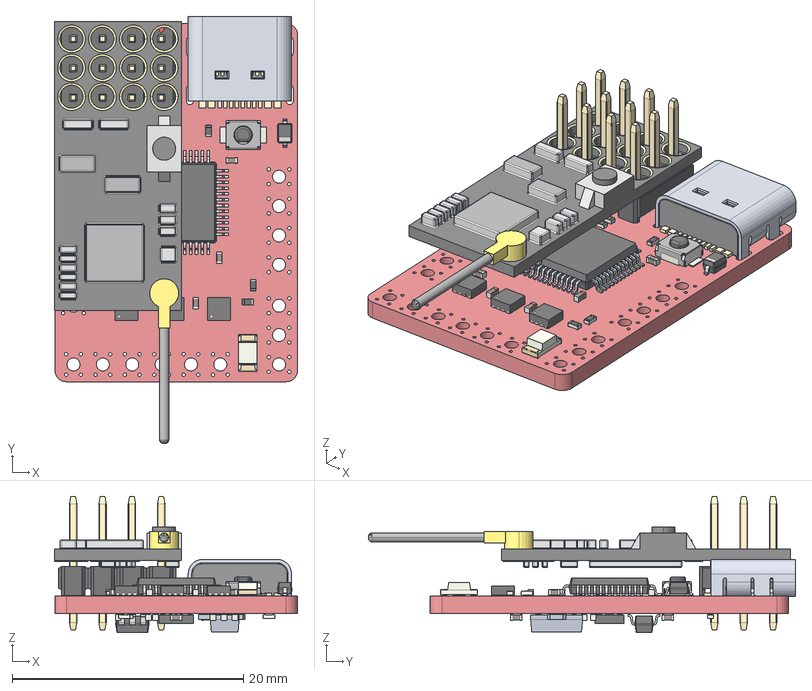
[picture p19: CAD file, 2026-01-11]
HARDWARE V2/ant control board v2.1/FAC v2.1 with FS2A.step
21.0 x 36.9 x 11.8 mm
C_0402_1005Metric x 18
R_0402_1005Metric x 11
usb-c
D_SOD-323
flysky 4CH reciever
DS1021_black_3x04p_100mil_Type1_rev1.0
SW_SPST_B3U-1000P
LQFP-48_7x7mm_P0.5mm
WSON-8-1EP_2x2mm_P0.5mm_EP0.9x1.6mm x 3
LED_1206_3216Metric
SOT-23-5
FAC v2.1 with FS2A 1.33.1
LGA-14_3x2.5mm_P0.5mm_LayoutBorder3x4y
ant control board v2_PCB

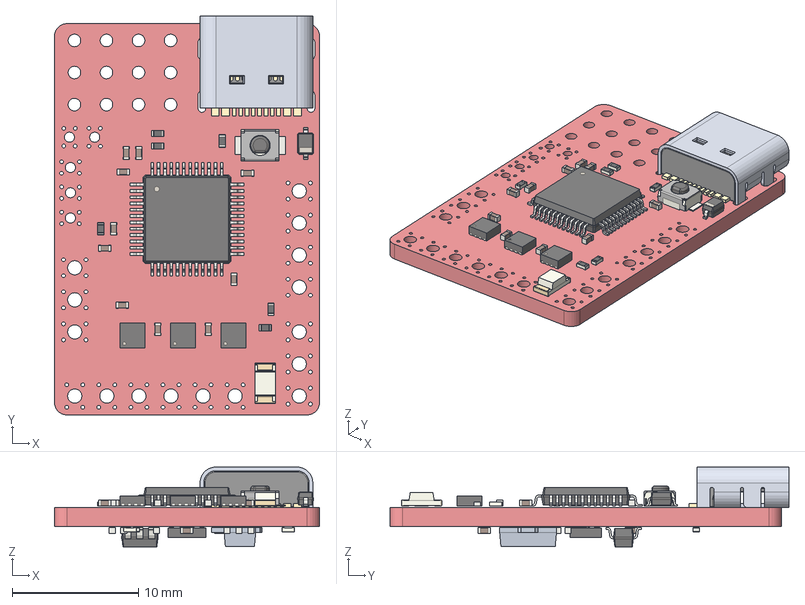
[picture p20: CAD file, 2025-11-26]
HARDWARE V2/ant control board v2.1/ant control board v2.step
21.0 x 31.6 x 6.34 mm
C_0402_1005Metric x 18
R_0402_1005Metric x 11
usb-c
D_SOD-323
SW_SPST_B3U-1000P
LQFP-48_7x7mm_P0.5mm
WSON-8-1EP_2x2mm_P0.5mm_EP0.9x1.6mm x 3
LED_1206_3216Metric
SOT-23-5
ant control board v1.3 1.31.1
LGA-14_3x2.5mm_P0.5mm_LayoutBorder3x4y
ant control board v2_PCB

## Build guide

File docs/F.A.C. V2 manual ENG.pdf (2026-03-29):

www.floppylab.it | thefloppylab@gmail.com

## Floppy Ant Controller

F.A.C. V2 manual

Advanced control board for combat robots

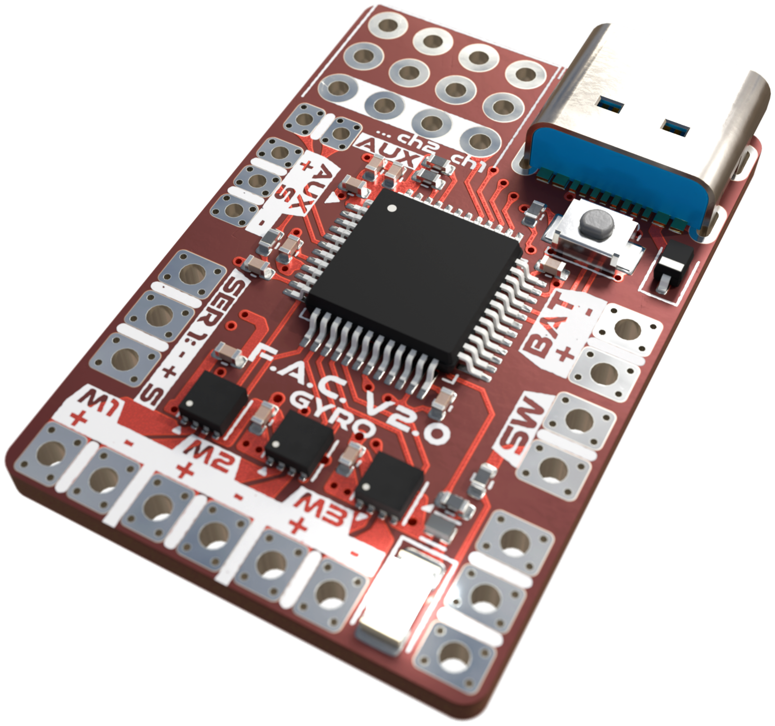
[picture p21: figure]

# Introduction

The FAC (Floppy Ant Controller) is a control board for combat robots, intended as a more advanced alternative to the Malenki-nano, (https://github.com/MarkR42/malenki-nano) while maintaining a competitive cost.

The FAC allows for a very advanced degree of freedom and customization. This allows it to be used as a control board for a wide variety of combat robots.

All settings can be conveniently changed via USB using the dedicated FAC tool, (https://factool.floppylab.it/) the tool dedicated to FAC settings.

As the firmware releases progress, new features will be added, including the use of the built-in accelerometer/gyroscope. Since it's an open-source project, anyone can modify it.

For the publication of content derived from this project, please consult the conditions established by the LICENSE (https://github.com/FloppyO1/Floppy-Ant-Controller/blob/main/LICENSE) file.

Last modified 292/3/2026 | for firmware version 2.0.7 and subsequent

# Definitions

➔ FAC: Acronym for Floppy Ant Controller, the control board of the project.
➔ DC motor: DC motor, e.g. N20/N10/N30 etc.
➔ Servo output: Typical control signal for servomotors: a pulse between 1 e 2 ms, with a frequency of 50 Hz, which determines the position of the servo.
➔ Cut-OFF: FAC security status.
When the FAC is in Cut-Off, it is disarmed and cannot be armed remotely. To exit this state, you must turn the FAC off and on again.
➔ Connection: A physical connection of the FAC is a connector on the board, used to connect motors, servos or ESCs via soldered wires.
➔ Output: The output is a value generated by a MIX or a Special Function. This value is associated with a physical connection on the FAC and translates into the movement of a motor or servo.
➔ IMU: Acronym for Inertial Measurement Unit: a sensor that integrates an accelerometer and a gyroscope to measure accelerations and angular velocities.
➔ Firmware: The program loaded into the FAC, which defines its operation and the available functions.

# Specifications

- 3 outputs for DC motors:
- 1.8A max
- 1000 steps per direction (resolution)
- adjustable frequency (100->10,000 Hz)
- 2 servo outputs:
- HV (battery powered)
- 1000 steps (resolution)
- adjustable pulse width
- adjustable frequency
- 2 digital inputs:
- 3.3V max
- 1 analog input:
- 3.3V max
- easy connection for potentiometers
- Basic version supports 1-2S lipo batteries (limited by DC drivers):
- adjustable CUT-OFF threshold
- adjustable CUT-OFF time
- High brightness status LED
- Compatible with various receivers:
- PPM up to 8 channels
- PWM up to 4 channels
- ELRS (not yet implemented)
- Settings can be easily changed via a dedicated tool https://factool.floppylab.it/ with USB-C cable:
- FAC Tool can also be used offline by saving it as an application
- No installation required
- Compact size and weight:
- 21mm * 31mm
- 2.4g without receiver, 3.6g with FS2A receiver

# New features

With this new version of the FAC, both the hardware and firmware have been completely redesigned.

This has allowed the introduction of new features, the most significant of which are the integration of an IMU (Inertial Measurement Unit), a sensor that includes a gyroscope and accelerometer, and the possibility of complete configuration in every aspect.

Thanks to these features, it's possible to develop customized algorithms for more advanced robot control. For example, a MIX is already under development that automatically reverses steering control in robots that can move even when upside down.

# Security features

The FAC integrates important safety features, designed to make using robots as safe as possible.

## FAC Activation

Once powered on, the FAC begins the startup procedure. Once startup is complete, it forces the card into the disarmed state until the receiver generates at least one channel that is not zero.

FS2A receivers and all model receivers do not generate any signal until the remote control is connected, so this feature has been used to check when the remote control is turned on and connected.

Therefore, the FAC cannot be armed until the remote control is connected. This makes the robot very safe in case it is accidentally turned on without the remote control being active.

## Arming e FAIL SAFE

Since the FAC does not have direct communication with the receiver chip, it cannot detect if the remote control loses connection.

For this purpose, the receiver's Fail Safe function, when appropriately configured, is used, which puts the FAC into a safe operating state in the event of a connection loss.

If the arming channel is active and assigned to a radio control channel, when the receiver enters Fail Safe the value of this channel must fall below the 80% threshold so that the robot is automatically disarmed.

## Watchdog

The FAC uses the so-called Watchdog, a hardware peripheral internal to the microcontroller that verifies that the firmware is running correctly.
If the firmware crashes for more than 500 ms, the Watchdog resets the FAC, preventing the robot from going out of control.

This feature significantly increases safety during combat and reduces the risk of defeat in the event of errors in the firmware execution.

## Battery CUT-OFF

To protect lithium batteries from over-discharging, which could cause them to swell and become dangerous, the FAC monitors the battery voltage.

If the voltage drops below the set threshold for more than the time at the cut-off,The FAC disarms and cannot be remotely rearmed.

It can only be reactivated by turning the FAC off and on again, but if the voltage remains below the threshold it will automatically return to cut-off, preventing damage to the battery.

This feature can be disabled by setting the cut-off threshold to 0V using the FAC Tool, but doing so is not recommended.

# Operating states

The FAC can be found in different operating states. Each is characterized by a flashing pattern of the status LED or a sound effect generated by the connected motors.

Starting from when the FAC is powered, the states it can be found in are the following:

### 1. Start 2. Unarmed 3. Army 4. Cut-Off

## Start

As soon as power is applied to the FAC, a startup routine is performed that includes several checks. Each check is characterized by different flash patterns based on different situations:

➔ Loading settings from EEPROM memory:
◆ 3 Quick Flashes: reading settings already stored
◆ 10 Quick Flashes: writing default settings to memory, empty memory (You should never see this flashing; if you do, it means there is a problem with the EEPROM. The following flashing occurs only when a new firmware version is being loaded)
➔ IMU initialization:
◆ 1 Long Flash: accelerometer zero calibration
◆ 20 Flashes Medium Speed: IMU initialization error. The IMU will not be used; the values read will always be 0. (It may be corrupted or there is a temporary error in its initialization. If rebooting the board doesn't fix it, the problem may be permanent.) ➔ Boot procedure completion:
◆ Boot end buzzer: Once the boot procedure is complete, the FAC emits a buzzer through the connected DC motors. Subsequently, the FAC will not arm until the remote control is connected.

If everything is working correctly you should have the following sequence of flashes/sounds:3 quick flashes ____ 1 long flash ____ end of start-up ringtone.

## Disarmed

Once the startup sequence is complete, the FAC is disarmed by default. It will remain disabled until at least one of the receiver's channels is not 0.

When the FAC is disarmed, all motors and servo outputs are completely disabled (no signal is generated). In this state, the battery voltage is not monitored, so the Cut-OFF state can never be activated.

➔ When the FAC is disarmed the status LED flashes slowly with a 2-second period, and a repeating sound is emitted every second from the connected DC motors.

To arm the FAC (and therefore exit the disarmed state), there are two possibilities dictated by the “arming channel” setting used In both cases, the remote control must be connected to the receiver:

### 1. Arming channel active: a channel is used to remotely arm the FAC, in

this case only if the chosen remote control channel rises above 80%, the FAC switches to the ARMED state.

### 2. Arming channel disabled: the FAC automatically arms itself after

completing the start-up sequence after a flash and a single sound from the connected DC motors.

## Armed

When the FAC is armed, it means that all the DC motor and servo connections are active and functional, so if the FAC is properly set, you can make the connected motors and servos/ESCs move. This is the active state when using the robot normally during a battle.

➔ When the FAC is armed the status LED remains always on and flickers every second (basically, it turns off for a short time and then turns back on). No noise is generated.
➔ When the FAC is armed and the battery is low the status LED flashes every second. (Low battery is different from dead battery, which is the cut-off)

When the FAC is armed, it checks the battery voltage to activate the CUT-OFF state if the battery drops below the set threshold for more than the set time, and checks the “arming channel” (if active), and if its value drops below 80%, the FAC returns to the state disarmed.

## CUT-OFF

When the FAC is in CUT-OFF it is as if it were disarmed, that is, all its controls are disabled so the robot cannot move and the weapon is stationary.

The difference is that once it enters this state, it cannot go back, because it is an emergency state that serves to preserve the battery and prevent it from becoming irreparably damaged.

The only way to restore normal operation of the FAC is to turn it off and on again.

➔ When it is in cut-OFF the LED flashes quickly (about every 0.5s) and the connected DC motors beep about every 0.5s.

# Electrical connection

To correctly connect the components (servo motors, ESC, batteries, switches) to the FAC, simply follow the instructions written on it.

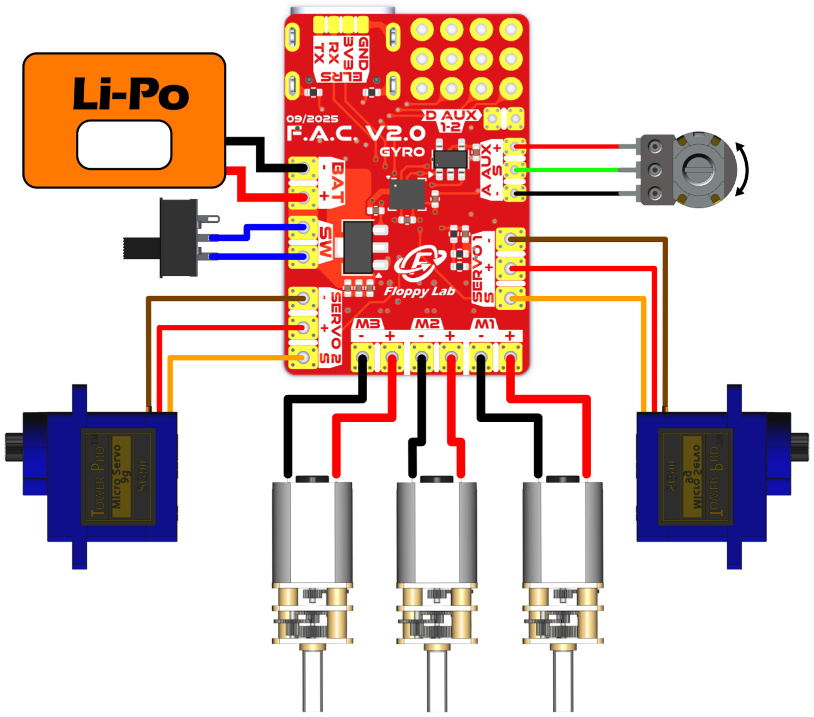
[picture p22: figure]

## Battery and switch

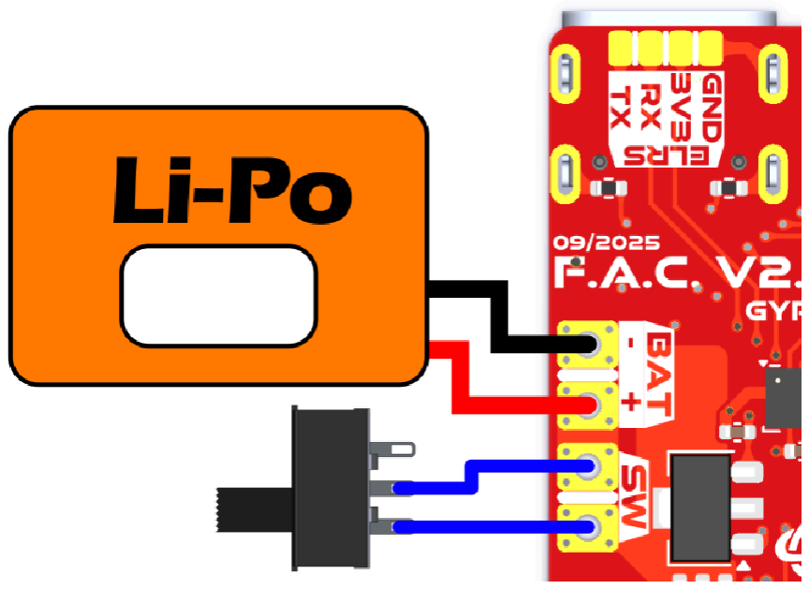
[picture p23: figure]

The battery and the switch are connected close to each other.

The battery (BAT) can be a maximum of 2S (7.4V nominal). If larger batteries are used, the FAC and the components connected to it may be permanently damaged.
It is necessary to respect the marked polarity, otherwise the FAC and the connected components may be permanently damaged. The FAC does not have reverse polarity protection, so be very careful.

The switch (SW) has no polarity and is used to disconnect the battery from the board, so if the switch is not closed, or not mounted, the FAC will not turn on. If you do not want to use a switch with the appropriate connections provided, you must short-circuit the two SW connections for the FAC to turn on.

## Servo/ESC

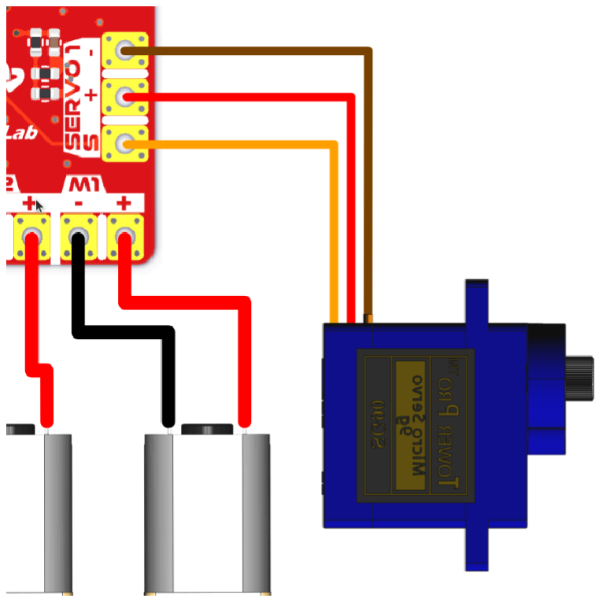
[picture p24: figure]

The servomotors must be connected following the graphics shown on the FAC. The servo connections are marked as SERVO 1 and SERVO 2.

The connections marked + and - are the power connections. The + is connected directly to the voltage coming from the battery (downstream of the switch), so be careful to use servos or ESCs that support this voltage.

The connection marked with the letter S is the control signal.

Be very careful not to short-circuit the connections together as this could irreparably damage the FAC and the components connected to it.

## DC motors

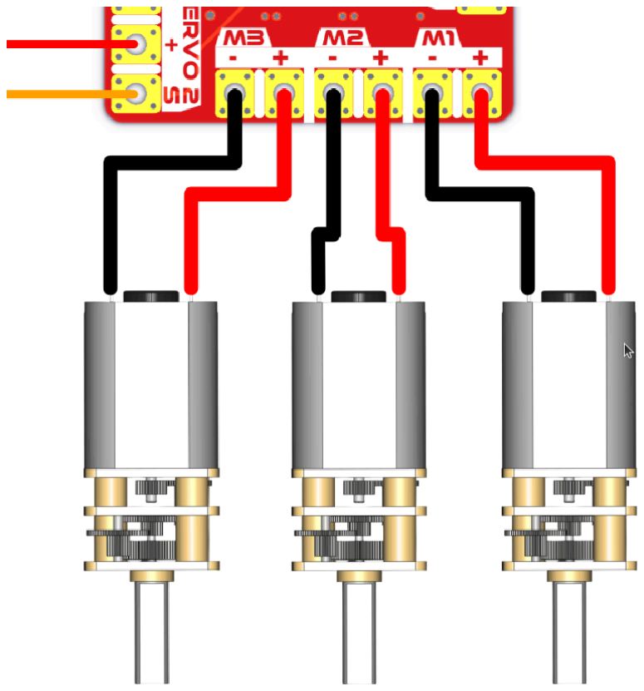
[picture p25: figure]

DC motors can be connected to the respective connections marked as M1, M2, M3.

It is recommended to respect the polarity for easier configuration, if they are connected with reverse polarity the direction of rotation is reversed.

Be careful not to short-circuit the connections between them, although they are less critical than the servo connections it is still strongly discouraged to do so.

## Receiver

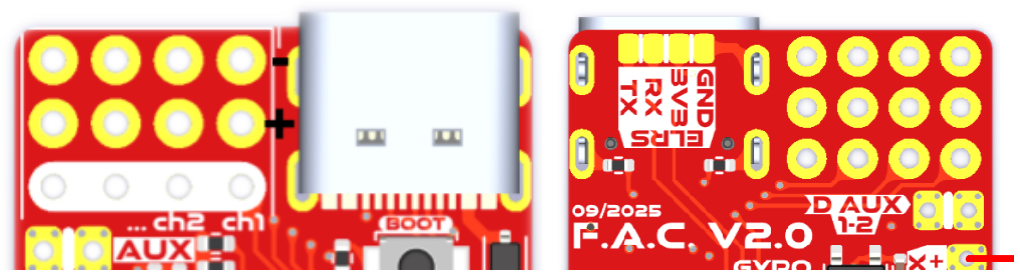
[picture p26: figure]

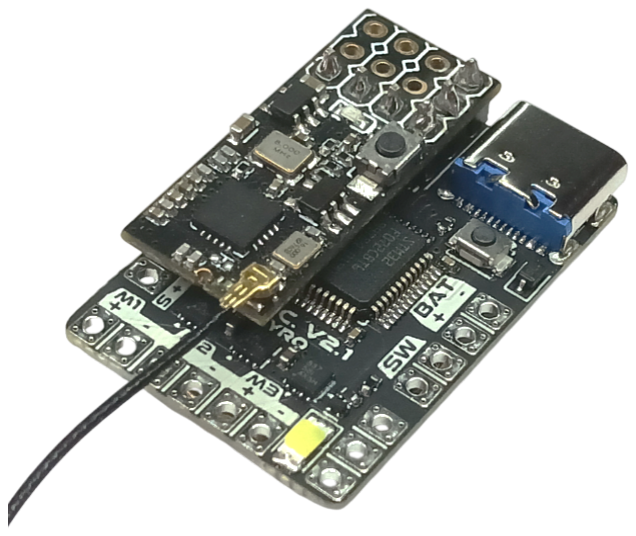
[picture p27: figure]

Many types of receivers can be connected to the FAC V2. It is primarily designed to mount an FS2A receiver directly above the connector as shown in the photo. However, other receivers can be connected using wires soldered to the dedicated connections.

You can use 4 channels with PWM receivers, and up to 8 channels with PPM receivers connected to channel 1.

The FAC supplies 3.3V (150mA max) of power to the receiver connections. It is extremely important to observe the correct polarity to avoid irreparably damaging the FAC. The first image above shows the polarity provided by the receiver connector.

It is also possible to connect an ELRS receiver, but the protocol management has not yet been implemented in the firmware, so it cannot be used yet.

## Analog and digital auxiliary inputs

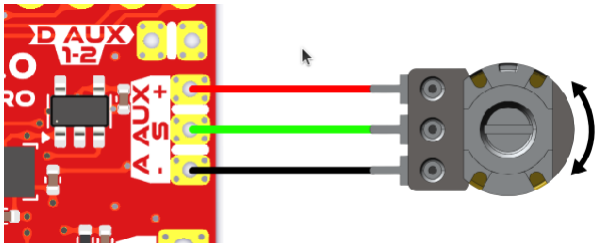
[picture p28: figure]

The FAC provides one analog input and two auxiliary digital inputs, for additional future or custom functionality.These inputs support signals with a maximum voltage of 3.3V, if this threshold is exceeded it is very likely that the FAC will be irreparably damaged.

The analog input was designed and built to make the use of an external potentiometer quick and easy, in order to have feedback for a possible servomotor made with DC motors.This feature is already under development, so it will be made available in future firmware releases.

The two digital inputs can also be used for specific functions and automation controls. These have not yet been implemented in the firmware, but may be in future versions.

# FAC TOOL

The FAC tool is a web application that allows you to connect any PC with a Chrome-based browser to the FAC, and change its settings with a convenient graphical interface.

This application can be found at the following link: https://factool.floppylab.it/ and you can download and use it offline by pressing the icon in the top right corner of the browser in the address bar.

This application allows you to modify all FAC settings and preview connections based on the chosen configuration. The preview can be
downloaded and/or printed by pressing the

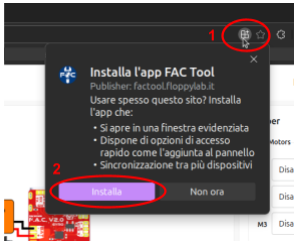
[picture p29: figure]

printer button in the top right of the preview.

The FAC tool also allows you to activate and deactivate telemetry from the FAC in real time. Telemetry (when active) updates approximately five times per second. In addition to providing the value read from all receiver channels, telemetry provides the battery voltage (total and individual cells, calculated as total/number of cells), the configuration of the connected battery (USB, 1S, 2S, 3S, 4S), and finally the status of the FAC (armed, disarmed, cutoff).On the side you can view the values read by the accelerometer mounted on the FAC by looking at the orientation of the 3D model of the FAC (not yet available).
NOTE! The FAC V2.x supports batteries up to 2S (7.4V nominal). Connecting a Li-Po/Li-ion battery with more than two cells may cause permanent damage to the FAC.

# How to connect the FAC V2 to the FAC tool

To connect the FAC V2 to the FAC tool and simply connect the USB-C port on the FAC to a PC with a USB data cable.

When connecting the FAC to a PC to modify its parameters using the FAC tool, it is recommended to also connect the battery to prevent it from being powered exclusively by the PC. The FAC is equipped with a protection diode to prevent current from flowing from the battery to the PC's USB port.

NOTE! When the FAC V2.x is powered by the PC (i.e. only the USB port is connected, no battery connected to the FAC), the DC motors and servo outputs are also powered by the PC's USB port, so keep in mind that the PC must provide all the current needed to power the motors/servos. It is recommended not to draw too much current from the PC as it could damage it irreparably. Do this at your own risk.

When testing new robot settings, always do so safely by blocking any blades or potentially dangerous parts.

Once the FAC is connected to the computer:

1. open the FAC tool (https://factool.floppylab.it/) and press the “Connect” button at the top left

### 2. select the device with the name “FAC_V2” and press connect

3. Please wait for all settings saved in the FAC to load.

Once everything is loaded, the settings you will see on the FAC tool will be the ones active in your FAC, now you can also activate telemetry.

Once you've modified the settings to suit your needs, you can press the "Test & Save" button. Once the procedure is complete, the settings will be activated and saved on the FAC, so you can test them (without disconnecting the FAC from the PC) and verify that they meet your needs.

If you want to return to the settings saved in the FAC's memory, simply press the "Read from FAC" button.

Once you've finished modifying the settings, you can press the "Disconnect" button and then disconnect the FAC from the PC.

# BASIC and ADVANCED settings

In the FAC, some basic settings have been implemented that are commonly found in almost all controllers (such as the Malenki-nano), (https://github.com/MarkR42/malenki-nano) but it also has other much more advanced features to make the setup of your controller more customizable based on the components used.

The settings have been divided into four categories, present in the FAC tool:

### 1. General 2. Mapping 3. Mix & Special Functions (Mix & SP. Functions) 4. Servo e Motori (Servos & Motors)

They are explained in more detail below. In the FAC tool, next to each setting, there is a symbol containing a description of the individual setting.

An example of a complete robot configuration using the mapper and all other functions can be found under the section Robot configuration example.

## General

The general settings are those that allow the FAC to function correctly, therefore they are the first to be adjusted on a new configuration.

The various settings are listed and explained below. The name of the setting found within the FAC tool is shown in bold.

## Battery (battery)

➔ Low battery voltage: is the battery voltage at which it is considered flat. (The FAC behavior does not change)
➔ Cut-off voltage: This is the battery voltage at which it is considered completely flat. (When the cut-off event occurs, the robot is automatically disarmed, and cannot be armed without turning the FAC off and on again.)
➔ Cut-off detection time: if the battery voltage remains below the CUT-OFF voltage for this time, the FAC goes into CUT-OFF, meaning the robot is automatically disarmed.
➔ Battery calibration: This allows you to manually calibrate the voltage read by the board. Essentially, the value you enter is added to the voltage read by the board. Do not change this setting unless you know exactly what you are doing, as it could significantly alter the FAC’s behavior!

## Receiver (receiver)

➔ Receiver type: allows you to choose the type of receiver you are using. You can choose between several types:

◆ PWM, up to 4 channels;
◆ PPM, up to 8 channels;
◆ ELRS, not yet implemented;
◆ NRF24, not yet implemented.

For example, if you are using an FS2A receiver mounted directly above the FAC, with the receiver in PWM mode (the
default mode), you should select PWM. The same applies for
other modes.

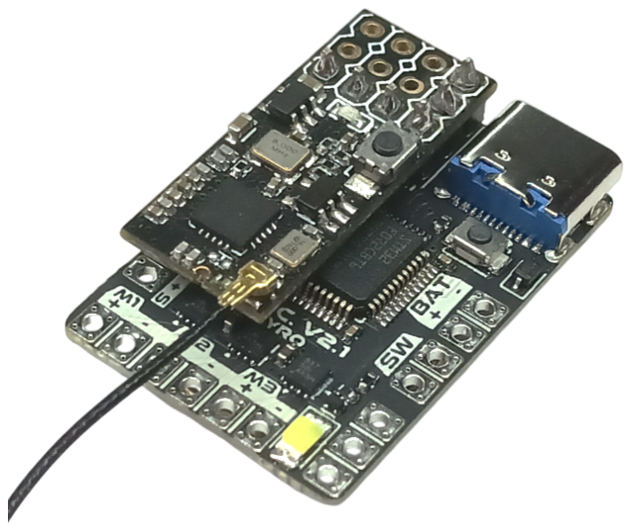
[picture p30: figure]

➔ Channels deadzone percentage: allows you to set a deadzone in the radio system channels to mitigate possible mis-centering of the radio control sticks. The deadzone is expressed as a percentage of the range (2% to 5% should be sufficient).
➔ Arming channel: You can use a channel read by the receiver to arm and disarm the FAC directly from the remote control. This feature can be disabled. If disabled, the FAC is immediately armed as soon as it is turned on. It disarms automatically when in CUT-OFF. When this setting is active, you must select the channel used for arming. In this case, the FAC arms when the selected channel has a value greater than 80% of its maximum value.

## Mapping

Mapping is used to decide where the outputs generated by the MIX and Special Functions will be used. That is, it allows us to decide whether to use the function/mix on a DC motor or a servo output.

All connections present in the FAC can be mapped as desired using the Mapper present on the right side of the FAC tool. There are three DC motor outputs and two servo outputs.

Each connection can be mapped to an output generated by a MIX or Special Function. An output can be mapped to multiple FAC
connections.

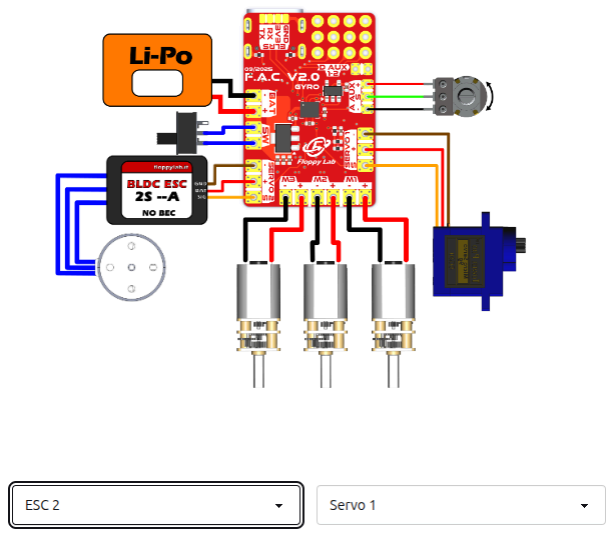
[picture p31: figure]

On the FAC tool there is a preview generated based on
the configuration chosen with the Mapper. The preview shows the various connections that need to be made on the FAC in order to use it on the robot with the chosen configuration. By pressing the printer icon, you can print the illustration with all the information needed for correct connection. Below the preview, you can choose whether to display a servomotor or an ESC+BLDC in the servo outputs. This option is purely for illustrative purposes and does not change any behavior of the FAC.

## MIX and SPECIAL FUNCTIONS

Depending on the installed firmware, the FAC can create different control signals via MIX and Special Functions.
These signals can command movements, such as the speed and direction of a motor or the position of a servo.

Finally, through the Mapper, it is possible to decide on which physical connectors of the FAC to send these signals.

Gradually, further MIXES and Special Functions will be added (if you have specific requests, please send an email to thefloppylab@gmail.com).

## Special Functions

A Special Function generates an output (only one), mappable with the Mapper, that allows you to add behaviors (automated or not) to the physical connections of the FAC.

The following are the Special Functions that can be activated:

➔ DC Servo: (not yet implemented) allows you to create a servomotor with a DC motor connected to the M1/M2/M3 outputs, controlling the position via the A.AUX analog input connected to a potentiometer. Control is performed via PID control. The position of the DC servo is set by the selected radio control channel.
➔ Direct link to channel: This special function is extremely useful for directly controlling servos and ESCs, as well as DC motors. It takes the signal from the selected channel and generates the output according to the logic shown below, depending on the use case. Up to eight "direct link to channel" functions can be activated.
The logic is slightly different depending on the connection
selected on the Mapper:

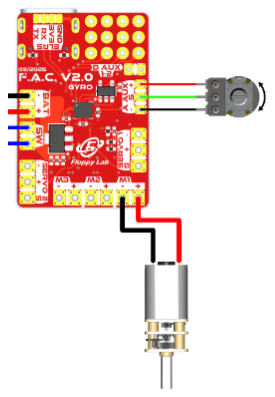
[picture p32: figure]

◆ DC motors: decideDirection and speed are directly proportional to the selected channel value. The central channel value is the engine stopped, up to the maximum and minimum values, which correspond respectively to maximum forward speed and maximum reverse speed.(motor direction can be reversed in settings Motors & Servos)

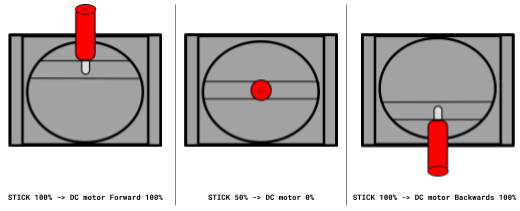
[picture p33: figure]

◆ servo: decide the servo position angle.
◆ ESC: decide the speed of the brushless motor connected to the ESC (also direction with the same logic as the DC motor in case the ESC is bidirectional).

## MIX

MIXES are used to decide the movement logic. They usually generate two or more outputs that can be selected with the Mapper on the physical connections of the FAC.

The following are the currently selectable MIXES:

➔ None: no MIX active. Does nothing.

➔ Simple Tank: this mix is used to calculate the speed and direction of the motors of a robot that uses only two wheels/squeaks (differential steering), i.e. it follows the movement logic of a tank's tracks. This mix therefore generates two outputs: right motor, left motor [Left Motor, Right Motor], which can then be assigned with the Mapper. Once activated, you can decide which radio control channel to associate with steering and throttle. In addition, you can decide whether or not to reverse these two channels, depending on your needs.

## Servos and Motors

These settings are related to modifying the behavior of the DC motor outputs and servo outputs.

The FAC V2 features two servo outputs, where you can connect servos and ESCs (Electronic Speed Controllers) for brushless or brushed motors. There are also three outputs for brushed (DC) motors.

The outputs of DC motors are PWM controlled to vary the speed of the motor.

The servo outputs provide the classic signal accepted by servomotors.

These two categories of outputs enjoy different settings.

## Engines

➔ Motors PWM frequency: You can choose the control frequency of the DC motors. You can choose a frequency ranging from 100Hz to 10,000Hz. This can be useful for specific calibration based on the motors used. For classic N20s, a frequency of 1000/2000Hz is sufficient.
➔ Reverse: Each DC output can be inverted by activating the reverse setting. If this is activated, the motor will rotate in the opposite direction to the value calculated by the MIX or Special Functions.
➔ Braking: Each DC output can be used to activate or deactivate the motor brake. The motor brake allows the motors to be stopped almost instantly once the speed is set to zero. The brake also provides greater control over the motor's rotation speed. If deactivated, the motor will also coast when you want to slow down the speed, thus providing less precise control.

## Servo

➔ Servos PWM frequency: You can choose the frequency of the generated servo signal. Some servos require (or support) a higher frequency than the classic 50Hz. A higher frequency allows for a greater update of the values. The frequency can be chosen from a minimum value of 20Hz to a maximum of 300Hz.
➔ Reverse: Each servo output can be reversed by activating the reverse setting. When activated, the servo will reverse its zero position with its maximum position.Pay close attention to this setting if you connect an ESC with a motor to these outputs. The motor may start at full speed, or the ESC may not activate at all and enter the settings if not configured correctly.. It is usually left unchanged if the radio control channels have not been reversed.
➔ Min μs value: to eachservant withThis setting defines the minimum pulse width of the generated servo signal. Some servo motors (especially the cheaper ones) require a pulse width other than the standard one (1ms -2ms). This setting defines the minimum pulse width. The value can be set from a minimum of 100μs to a maximum of 1499μs.
➔ Max μs value: to every servant withThis setting defines the maximum pulse width of the generated servo signal. Some servo motors (especially the cheaper ones) require a pulse width other than the standard one (1ms to 2ms). This setting defines the maximum pulse width. The value can be set from a minimum of 1501μs to a maximum of 2900μs.

# Robot configuration example

As a practical example, we use the Bretèllator robot, which is equipped with a rotating kinetic weapon and two wheels for a differential movement system.

Let's assume we have:

- two side wheels connected to two N20s
- a rotating kinetic weapon connected to a BLDC (brushless) motor controlled by an ESC
- an FS2A receiver in PWM mode (default mode)
connected to the FAC (4 channels available).

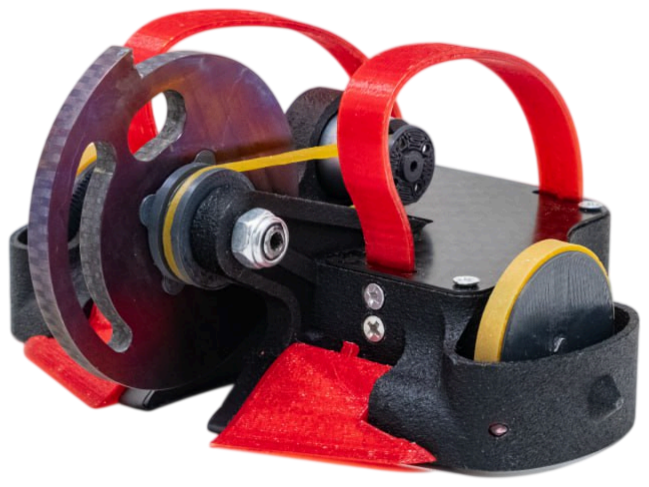
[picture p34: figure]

We choose to connect the right wheel motor on connection M1 and the left wheel motor on M3 connection. Finally the ESC that drives the weapon motor on servo connection 1.

### 1. We lock the weapon with the locking device and lift the robot so that it

does not touch the wheels.

### 2. We turn on the radio control and place it in a place where it cannot be

bumped and the position of the sticks cannot be changed.

### 3. Once the FAC is connected to the PC with a USB cable, keeping the

battery connected and the switch on, we start the FAC tool.

### 4. Remember that the FAC will not disarm until the receiver provides a

valid signal, which is when the remote control is turned on and properly connected. When it is turned on, the chime will be played by the connected DC motors.

### 5. Press "Connect" and select the FAC_V2 device. The FAC tool will now load

the FAC settings and allow you to configure everything. In the top right, you can check the firmware version installed on your FAC.

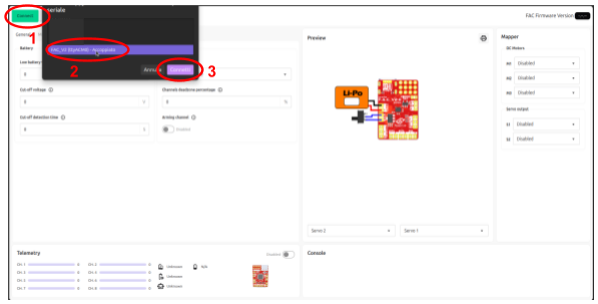
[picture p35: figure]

### 6. First of all we set the correct type of receiver, so in our case we go

to the tab “General” and under the “Receiver” box we select PWM as the type.

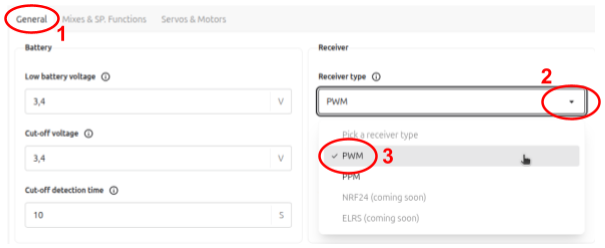
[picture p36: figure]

### 7. Since the FS2A doesn't have many channels in PWM mode (only four), we

disable the "Arming channel" option. This will automatically arm the FAC as soon as it's turned on, so we need to be very careful not to accidentally move the radio controls.

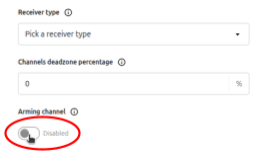
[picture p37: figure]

### 8. Now press the "Test & Save" button and activate telemetry. Now we can

check that the first four channels (CH.1-4) follow the position of the remote control sticks. If the remote control is already centered correctly, but when the sticks are at center the displayed value is not 500, or when they are at maximum it is not 999 or 0, we need to increase the deadzone percentage. Do this until the values are acceptable. It is not necessary to adjust the deadzone; usually a value between 2% and 5% is sufficient.

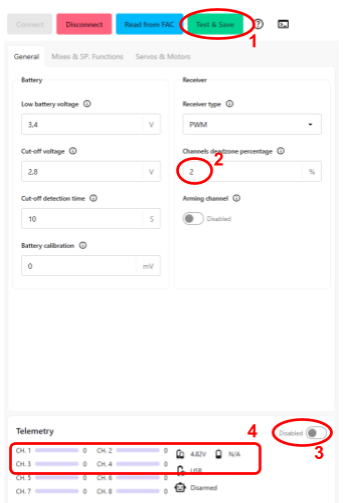
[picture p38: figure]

### 9. Now in the “Mix & SP.Functions” tab we will set the mix for the wheels

and the special function for the weapon. Then we activate the “Simple Tank” and then select the channels we want to use for the “Throttle” and “Steering” accelerator. If we have the radio control in Stick Mode 2, we have asacceleratorChannel 2, and channel 1 for steering. The special function that allows us to directly control the ESC with the springless stick of the radio control (i.e., channel 3) is a “Direct link to channel.” So we activate the first by pressing “Enable” and select

channel 3.

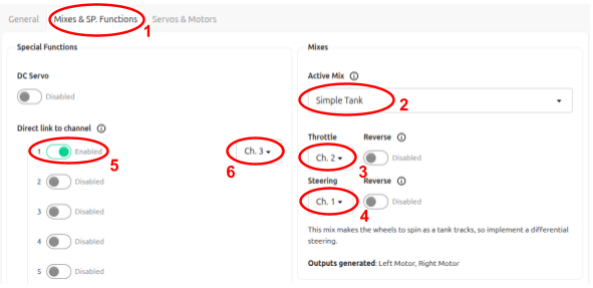
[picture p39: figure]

10.Now that we've generated the outputs, we can assign them to the FAC's physical connections. On the left side of the interface, we have the Preview and the Mapper. Within the mapper, we can associate the Special Functions and Mix outputs with the FAC's actual connections. Recalling the requirements, we had: M1 right engine, M3 left engine and servo 1 connected all’ESC del motore brushless. So on the M1 drop-down menu we select right motor (Motor right), on M3 we select left motor (Motor left), finally on S1 “Direct Link to CH. 1”, the unused ones should be set to “Disabled”. The connections on the preview should have been updated. To choose to display an ESC with motor instead of the servo, we can select “ESC 1” from the drop-down menu at the bottom (these two menus only set the graphics, nothing else).

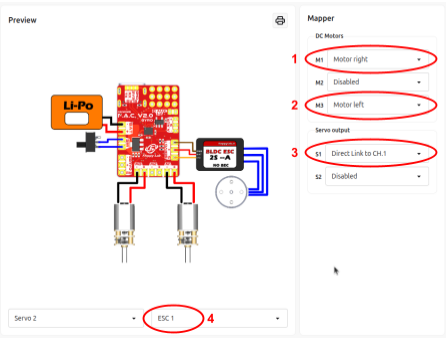
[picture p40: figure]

11.Now, as before, click "Test & Save," and if all the motors are turning correctly, you can press "Save to FAC." If the motors aren't turning correctly, you can reverse the rotation in the "Servos & Motors" tab by clicking the "Reverse" option for the desired motor, then test the settings again. I recommend enabling breaking on the DC motors used, so you have better control over their speed.
12.Now you have the FAC set up correctly and ready to battle inside your robot!

# Questions and Answers (Q & A)

## Firmware 2.0.7 and later

Q.I've set up the Tank Mix channels and motors correctly on the Mapper, but when I try to move forward, the robot spins. Should I swap the steering and throttle channels?
A.If you're sure you've selected the steering and throttle channels correctly, the problem is that one of the wheel motors is rotating backwards. Swap one of them in the "Servos & Motors" tab and you should be fine.
Q. I can't disarm the FAC. Why?
A. Check that you've connected the remote control properly. This happens because the FAC isn't receiving valid signals from the receiver, so the receiver may be disconnected.

## Firmware 2.0.5 and earlier

Q.The FAC tool freezes after connecting and won't read data from the FAC. Is the FAC broken?
A.No, the FAC isn't broken. For safety's sake, the FAC won't activate until it reads valid values from the receiver, so if the remote is off, the FAC won't turn on. Turn on the remote and make sure the receiver is connected. The FAC should play a song from the DC motors, and then the FAC tool will read the data.

# Information on the document

This manual was written by Floppy Lab™ to provide information on the use and functionality of the FAC.

All the project files can be found at: https://github.com/FloppyO1/Floppy-Ant-Controller

About changes, suggestions or feedback, write to: thefloppylab@gmail.com

Follow us on our social media channels:

- Instagram: the_floppy_lab (https://www.instagram.com/the_floppy_lab/)
- YouTube: @floppylab (https://www.youtube.com/@floppylab)
- GitHub: FloppyO1 (https://github.com/FloppyO1)
- Website:www.floppylab.it

Thank you for your support and for choosing Floppy Lab projects!

This project is released under the terms of the license included in the official repository. Please refer to the LICENSE file on GitHub (https://github.com/FloppyO1/Floppy-Ant-Controller) for usage and redistribution rights.

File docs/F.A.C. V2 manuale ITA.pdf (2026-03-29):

www.floppylab.it | thefloppylab@gmail.com

## Floppy Ant Controller

F.A.C. V2 manuale

Scheda di controllo avanzata per robot da combattimento


# Introduzione

La FAC (Floppy Ant Controller) è una scheda di controllo per robot da combattimento, pensata come alternativa più avanzata della Malenki-nano, (https://github.com/MarkR42/malenki-nano) mantenendo un costo competitivo.

La FAC permette di avere un grado di libertà e personalizzazione molto avanzato. Questo permette di essere impiegata come scheda di controllo per una vastissima varietà di robot da combattimento.

Tutte le impostazioni possono essere modificate comodamente via USB con l’ausilio del FAC tool, (https://factool.floppylab.it/) lo strumento dedicato alle impostazioni della FAC.

Con l'avanzamento delle versioni del firmware verranno aggiunte nuove funzionalità che integrano anche l'utilizzo del accelerometro/giroscopio integrato. Essendo un progetto open source ognuno può modificarlo in autonomia.

Per la pubblicazione di contenuti derivati da questo progetto, consultare le condizioni stabilite dalla LICENZA. (https://github.com/FloppyO1/Floppy-Ant-Controller/blob/main/LICENSE)

ultima modifica 29/3/2026 | per versione firmware 2.0.7 e successive

# Definizioni

➔ FAC: Acronimo di Floppy Ant Controller, la scheda di controllo del progetto.
➔ Motore DC: motore in corrente continua, ad esempio N20/N10/N30 ecc. ➔ Uscita servo: Segnale di controllo tipico dei servomotori: un impulso compreso tra 1 e 2 ms, con frequenza di 50 Hz, che determina la posizione del servo.
➔ Cut-OFF: Stato di sicurezza della FAC.
Quando la FAC è in Cut-OFF, è disarmata e non può essere armata da remoto. Per uscire da questo stato è necessario spegnere e riaccendere la FAC.
➔ Connessione: Una connessione fisica della FAC è un connettore presente sulla scheda, utilizzato per collegare motori, servo o ESC tramite fili saldati.
➔ Uscita: L'uscita è un valore generato da un MIX o da una Funzione Speciale. Questo valore viene associato a una connessione fisica della FAC e si traduce nel movimento di un motore o di un servo.
➔ IMU: Acronimo di Inertial Measurement Unit: un sensore che integra accelerometro e giroscopio per misurare accelerazioni e velocità angolari.
➔ Firmware: Il programma caricato nella FAC, che ne definisce il funzionamento e le funzioni disponibili.

# Specifiche

- 3 uscite per motori DC:
- 1.8A max
- 1000 step per direzione (risoluzione)
- frequenza modificabile (100->10'000 Hz)
- 2 uscite servo:
- HV (alimentazione dalla batteria)
- 1000 step (risoluzione)
- larghezza dell'impulso modificabile
- frequenza modificabile
- 2 ingressi digitali:
- 3.3V max
- 1 ingresso analogico:
- 3.3V max
- connessione facile per potenziometri
- Versione base supporto batterie 1-2S lipo (limitata dai driver DC):
- soglia CUT-OFF impostabile
- tempo di CUT-OFF impostabile
- LED di stato ad alta luminosità
- Compatibile con diversi ricevitori:
- PPM fino ad 8 canali
- PWM fino a 4 canali
- ELRS (non ancora implementato, ma predisposto)
- Impostazioni modificabili facilmente tramite tool dedicato https://factool.floppylab.it/ con cavo USB-C:
- Tool utilizzabile anche offline, salvandolo come applicazione
- Nessuna installazione necessaria
- Dimensioni e peso contenuti:
- 21mm * 31mm
- 2.4g senza ricevitore, 3.6g con ricevitore FS2A

# Nuove funzionalità

Con questa nuova versione della FAC, sia l’hardware che il firmware sono stati completamente riprogettati.

Questo ha permesso di introdurre nuove funzionalità, tra cui le più rilevanti sono l’integrazione di una IMU (Inertial Measurement Unit), un sensore che include giroscopio e accelerometro, e la possibilità di una configurazione completa in ogni suo aspetto.

Grazie a queste caratteristiche è possibile sviluppare algoritmi personalizzati per un controllo più avanzato del robot. Ad esempio, è già in fase di sviluppo un MIX che inverte automaticamente il comando dello sterzo nei robot in grado di muoversi anche quando sono capovolti.

# Funzionalità di sicurezza

La FAC integra importanti funzionalità di sicurezza, progettate per rendere l’utilizzo dei robot il più sicuro possibile.

## Attivazione FAC

La FAC una volta alimentata, procede con la procedura di avvio. Una volta terminato l’avvio forza la scheda nello stato disarmato finché il ricevitore non genera almeno un canale diverso da zero.

Le riceventi FS2A e tutti i ricevitori da modellismo finché il radiocomando non si collega, non generano alcun segnale, quindi è stata sfrutta questa caratteristica per controllare quando il radiocomando è acceso e collegato.

Quindi non si potrà armare la FAC non finché il radiocomando non è collegato. Questo rende molto sicuro il robot quando viene acceso accidentalmente senza radiocomando acceso.

## Arming e FAIL SAFE

Non avendo una comunicazione diretta con il chip del ricevitore, la FAC non può rilevare se il radiocomando, dopo essere stato acceso e collegato, perde la connessione.

Per questo viene utilizzata la funzione di Fail Safe del ricevitore, opportunamente configurata, che porta la FAC in uno stato di funzionamento sicuro in caso di perdita del collegamento.

Se l’arming channel è attivo e assegnato a un canale del radiocomando, quando il ricevitore entra in Fail Safe il valore di questo canale deve scendere sotto la soglia dell’80% così il robot viene disarmato automaticamente.

## Watchdog

La FAC utilizza il cosiddetto Watchdog, una periferica hardware interna al microcontrollore che verifica che il firmware sia in esecuzione correttamente. Se il firmware dovesse bloccarsi per più di 500 ms, il Watchdog resetta la FAC, evitando che il robot rimanga fuori controllo.

Questa funzione aumenta notevolmente la sicurezza durante i combattimenti e riduce il rischio di sconfitta in caso di errori nell’esecuzione del firmware.

## Cut Off batteria

Per proteggere le batterie al litio da scariche eccessive, che potrebbero farle gonfiare e diventare pericolose, la FAC monitora la tensione della batteria.

Se la tensione scende sotto la soglia impostata per più del tempo di cut-off, la FAC si disarma e non può essere riarmata da remoto.

Può essere riattivata solo spegnendo e riaccendendo la FAC, ma se la tensione rimane sotto la soglia tornerà automaticamente in cut-off, prevenendo danni alla batteria.

Questa funzione può essere disattivata impostando la soglia del cut-off a 0 V tramite il FAC Tool, ma non è consigliato farlo.

# Stati di funzionamento

La FAC si può trovare in diversi stati di funzionamento. Ognuno è caratterizzato da una modalità di lampeggio del LED di stato, oppure da un effetto sonoro generato dai motori collegati.

Partendo da quando viene alimentata la FAC, gli stati in cui si può trovare sono i seguenti:

### 1. Avvio 2. Disarmata 3. Armata 4. Cut-Off

## Avvio

Appena viene collegata l’alimentazione alla FAC, viene eseguita una routine di avvio che comprende dei controlli. Ogni controllo è caratterizzato da dei tipi di lampeggio differenti in base a diverse situazioni:

➔ Caricamento delle impostazioni dalla memoria EEPROM:
◆ 3 Lampeggi veloci: lettura impostazioni già memorizzate
◆ 10 Lampeggi veloci: scrittura impostazioni di default in memoria, memoria vuota (non si dovrebbe mai vedere questo lampeggio, se si vede vuol dire che c’è un problema con la memoria EEPROM. Il seguente lampeggio si presenta soltanto quando viene caricata una nuova versione del firmware)
➔ Inizializzazione della IMU:
◆ 1 Lampeggio lungo: calibrazione dello zero del accelerometro
◆ 20 Lampeggi media velocità: errore nell’inizializzazione della IMU. L'IMU non verrà utilizzata, i valori letti saranno sempre 0. (può essere danneggiata oppure un errore temporaneo nella sua inizializzazione, se riavviando la scheda non risolve, il problema potrebbe essere permanente)
➔ Termine della procedura d’avvio:
◆ Suoneria di fine avvio: una volta terminata la procedura di avvio la FAC emette una suoneria attraverso i motori DC collegati. Successivamente la FAC non si armerà finché il radiocomando non sarà connesso.

Se tutto è correttamente funzionante si dovrebbe avere la seguente sequenza di lampeggi/suoni: 3 lampeggi veloci ____ 1 lampeggio lungo ____ suoneria fine avvio.

## Disarmata

Terminata la sequenza di avvio, la FAC è di default disarmata. Rimarrà forzatamente disarmata finché almeno uno dei canali del ricevitore non diventa diverso da 0.

Quando la FAC è disarmata, tutti i motori e uscite servo sono completamente disabilitate (non viene generato alcun segnale). In questo stato la tensione della batteria non viene controllata, quindi non si può mai attivare lo stato di Cut-OFF.

➔ Quando è disarmata il LED di stato lampeggia lentamente con un periodo di 2 secondi, e viene emesso un suono ripetuto ogni secondo proveniente dai motori DC collegati.

Per poter armare la FAC (quindi uscire dallo stato disarmo), ci sono due possibilità dettate dall’impostazione “arming channel” utilizzata. In entrambi i casi il radiocomando deve essere collegato al ricevitore:

### 1. Arming channel attivo: viene utilizzato un canale per armare da remoto

la FAC, in questo caso soltanto se il canale del radiocomando scelto sale sopra al 80% la FAC passa allo stato ARMED (Armata).

### 2. Arming channel disattivato: la FAC appena termina la sequenza di avvio

si arma automaticamente dopo un lampeggio ed un suono singolo proveniente dai motori DC collegati.

## Armata

Quando la FAC è armata, vuol dire che tutte le connessioni dei motori DC e dei servo sono attive e funzionanti, quindi se la FAC è opportunamente impostata, si può far muovere i motori e servo/ESC collegati. Questo è lo stato attivo quando si utilizza il robot normalmente durante una battaglia.

➔ Quando la FAC è armata il LED di stato rimane sempre acceso e fa come uno sfarfallio ogni secondo (in pratica si spegne per pochissimo tempo e poi si riaccende). Non viene generato alcun rumore.
➔ Quando la FAC è armata e la batteria è scarica il LED di stato lampeggia ogni secondo. (batteria scarica è diverso da batteria esaurita ovvero il cut-off)

Quando la FAC è armata, viene controllata la tensione della batteria per attivare lo stato di Cut-OFF se la batteria scende sotto la soglia impostata per più del tempo impostato, e controlla il “arming channel” (se attivo), e se il suo valore scende sotto l’80%, la FAC ritorna allo stato disarmata.

## Cut-OFF

Quando la FAC è in cut-OFF è come se fosse disarmata, ovvero tutti i suoi controlli sono disabilitati quindi il robot non si può muovere e l’arma è ferma.

La differenza è che una volta entrata in questo stato, non può tornare indietro, perché è uno stato di emergenza che serve per preservare la batteria ed evitare che si danneggi irreparabilmente.

L’unico modo per poter ripristinare il normale funzionamento della FAC è di spegnerla e riaccenderla.

➔ Quando è in cut-OFF il LED lampeggia velocemente (ogni 0.5s circa) e i motori DC collegati emettono un beep ogni circa 0.5s.

# Collegamenti

Per collegare correttamente i componenti (motori servo, ESC, batterie, interruttori) alla FAC è sufficiente seguire le indicazioni scritte su di essa.


## Batteria e interruttore


La batteria e l’interruttore sono collegati vicini uno all’altro.

La batteria (BAT) può essere al massimo una 2S (7.4V nominali) se vengono utilizzate batterie più grandi si può danneggiare irreparabilmente la FAC e i componenti a lei collegati.
È necessario rispettare la polarità segnata altrimenti si può danneggiare irreparabilmente la FAC e i componenti a lei collegati. La FAC non è provvista di protezione contro la connessione inversa della polarità, quindi fare molta attenzione.

L’interruttore (SW) non ha polarità e serve a scollegare la batteria dalla scheda, quindi se l’interruttore non è chiuso, oppure non è montato, la FAC non si accende. Se non si vuole utilizzare un interruttore con gli appositi collegamenti forniti, è necessario cortocircuitare i due collegamenti SW per fare sì che la FAC si accenda.

## Servo/ESC


I servomotori vanno collegati seguendo la grafica riportata sulla FAC. Le connessioni servo sono segnate come SERVO 1 e SERVO 2.

Le connessioni segnate come + e - sono quelle di alimentazione. Il + è collegato direttamente alla tensione proveniente dalla batteria (a valle dell’interruttore) quindi attenzione ad utilizzare servomotori oppure ESC che supportino tale tensione.

La connessione segnata con la lettera S è il segnale di controllo.

Fare molta attenzione a non cortocircuitare tra di loro le connessioni si può danneggiare irreparabilmente la FAC e i componenti a lei connessi.

## Motori DC


I motori DC possono essere collegati alle rispettive connessioni segnate come M1, M2, M3.

Si consiglia di rispettare la polarità per una più facile configurazione, se vengono collegati con polarità inversa la direzione di rotazione viene invertita.

Fare attenzione a non cortocircuitare le connessioni tra di loro, pur essendo meno critiche delle connessioni servo è comunque vivamente sconsigliato farlo.

## Ricevitore


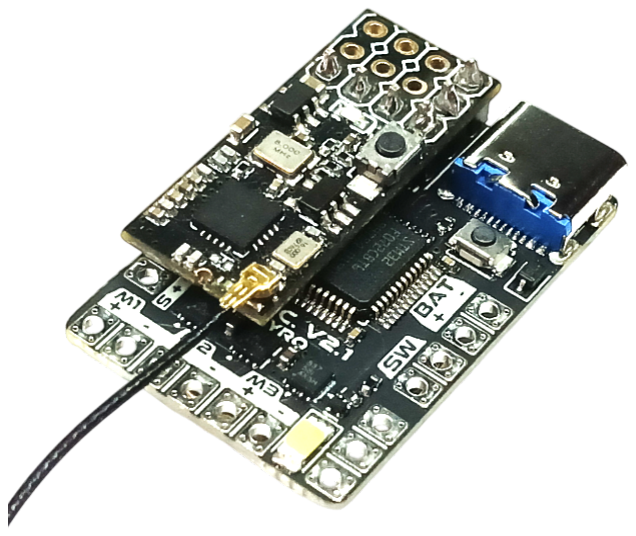
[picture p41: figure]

Alla FAC V2 si possono collegare molti tipi di ricevitori. È stata principalmente progettata per montare una ricevente FS2A direttamente al di sopra del connettore come in foto. Ma si possono collegare altri ricevitori con dei cavetti saldati sulle connessioni dedicate.

È possibile utilizzare 4 canali con ricevitori PWM, e fino ad 8 canali con ricevitori PPM collegati al canale 1.

La FAC fornisce 3.3V (150mA max) di alimentazione alle connessioni destinate al ricevitore. È estremamente importante seguire le corrette polarità per non danneggiare irreparabilmente la FAC. Nella prima immagine qui sopra si vede la polarità fornita dal connettore per il ricevitore.

È possibile collegare anche un ricevitore ELRS, però non è stata ancora implementata nel firmware la gestione del protocollo, quindi non si può ancora utilizzare.

## Ingressi ausiliari analogici e digitali

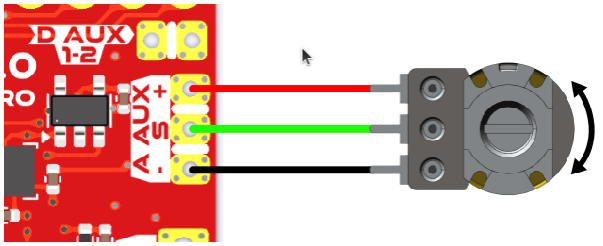
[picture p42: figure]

La FAC mette a disposizione un ingresso analogico e due digitali ausiliari, per ulteriori funzionalità future o personalizzate. Questi ingressi supportano segnali con una tensione massima di 3.3V, se questa soglia viene superata è molto probabile che la FAC si danneggi irreparabilmente.

L’ingresso analogico è stato pensato e realizzato per rendere facile e veloce l’utilizzo di un potenziometro esterno, per poter avere un feedback per un eventuale servomotore realizzato con motori DC. Questa funzionalità è già in sviluppo, quindi nelle future versioni del firmware verrà resa disponibile.

I due ingressi digitali possono essere usati anch’essi per funzioni specifiche e controlli per degli automatismi. Questi non sono stati ancora impiegati nel firmware, ma in future versioni lo potranno essere.

# FAC TOOL

Il FAC tool è un’applicazione web che permette di collegare un qualsiasi PC con un browser basato su Chrome alla FAC, e cambiarne le impostazioni con una comoda interfaccia grafica.

Questa applicazione si può trovare al seguente link: https://factool.floppylab.it/ e si può scaricare ed utilizzare offline premendo l’icona in alto a destra nel browser nella barra degli indirizzi.

Questa applicazione permette di modificare tutte
le impostazioni della FAC e visualizzare

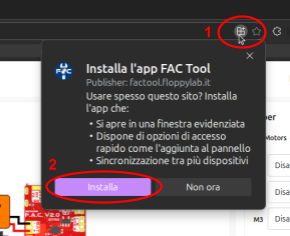
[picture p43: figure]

un'anteprima dei collegamenti basati sulla configurazione scelta. L’anteprima si può scaricare e/o stampare premendo il pulsante della stampante in alto a destra dell’anteprima.

Il FAC tool permette anche di attivare e disattivare la telemetria proveniente dalla FAC in tempo reale. La telemetria (quando attiva) si aggiorna circa cinque volte al secondo. La telemetria oltre a fornire il valore letto di tutti i canali del ricevitore, fornisce la tensione della batteria (totale e delle singole celle, calcolata come totale/numero di celle) la configurazione della batteria collegata (USB, 1S, 2S, 3S, 4S) infine lo stato della FAC (armata, disarmata, cutoff). Di fianco si possono visualizzare i valori letti dall’accelerometro montato sulla FAC guardando l’orientamento del modello 3D della FAC (non ancora disponibile).
NOTA BENE! La FAC V2.x supporta batterie fino a 2S (7.4V nominali), se viene collegata una batteria Li-Po/Li-ion con più di due celle la FAC potrebbe smettere di funzionare e danneggiarsi irreparabilmente.

# Come collegare la FAC V2 al FAC tool

Per collegare la FAC V2 al FAC tool e sufficiente collegare la porta USB-C presente nella FAC ad un PC con un cavetto USB dati.

Quando la FAC viene collegata al PC per modificare i suoi parametri tramite FAC tool, si consiglia di collegare anche la batteria per evitare che venga alimentata esclusivamente dal PC. La FAC è provvista di un diodo di protezione per evitare che la corrente scorra dalla batteria verso la porta USB del PC.

NOTA BENE! La FAC V2.x quando alimentata dal PC (quindi soltanto la porta USB è connessa, nessuna batteria collegata alla FAC) anche i motori DC e le uscite servo vengono alimentati dalla porta USB del PC, quindi considerare che il PC deve fornire tutta la corrente necessaria per alimentare i motori/servo. Si suggerisce di non assorbire molta corrente dal PC in quanto potrebbe danneggiarlo irreparabilmente. Fate questo a vostro rischio e pericolo.

Quando testate le nuove impostazioni del robot fatelo sempre in sicurezza, bloccando lame o parti potenzialmente pericolose.

Una volta collegata la FAC al computer:

1. aprire il FAC tool (https://factool.floppylab.it/) e premere sul pulsante “Connect” in alto a sinistra

### 2. selezionare il dispositivo con il nome “FAC_V2” e premere connetti

3. attendere il caricamento di tutte le impostazioni salvate nella FAC.

Una volta caricato il tutto, le impostazioni che vedrete sul FAC tool saranno quelle attive nella vostra FAC, ora potete anche attivare la telemetria.

Una volta modificate le impostazioni in base alle vostre esigenze si può premere sul pulsante “Test&Save” e una volta terminata la procedura, le impostazioni sono state attivate e salvate sulla FAC, così si possono provare (senza scollegare la FAC dal PC) e verificare che siano coerenti con le esigenze.

Se si vuole tornare alle impostazioni salvate nella memoria della FAC è sufficiente premere il pulsante “Read from FAC”.

Una volta finita la modifica delle impostazioni si può premere sul pulsante “Disconnect” e poi si può scollegare la FAC dal PC.

# Impostazioni BASE e AVANZATE

Nella FAC sono state implementate delle impostazioni base che si trovano comunemente in un po' tutti i controller (come la Malenki-nano), (https://github.com/MarkR42/malenki-nano) ma ha anche altre funzionalità molto più avanzate per poter rendere più personalizzabile l'impostazione del proprio controller in base ai componenti utilizzati.

Le impostazioni sono state suddivise in quattro categorie, presenti nel FAC tool:

### 1. Generali (General) 2. Mappaggio (Mapping) 3. Mix e Funzioni speciali (Mix & SP. Functions) 4. Servo e Motori (Servos & Motors)

Qui sotto vengono spiegate più nel dettaglio. Nel FAC tool di fianco ad ogni impostazione si trova un simbolo dove si trova una descrizione della singola impostazione.

Un esempio di configurazione completa di un robot con l’utilizzo del mapper e tutte le altre funzioni si trova sotto la sezione Esempio configurazione robot.

## Generali

Le impostazioni generali sono quelle che permettono di far funzionare correttamente la FAC, quindi quelle da sistemare per prime su una nuova configurazione.

Qui sotto vengono elencate e spiegate le varie impostazioni. In grassetto è stato riportato il nome dell’impostazione che si trova all’interno del FAC tool.

## Battery (batteria)

➔ Low battery voltage: è la tensione della batteria alla quale viene considerata scarica. (non varia il comportamento della FAC)
➔ Cut-off voltage: è la tensione della batteria alla quale viene considerata completamente esaurita. (quando si verifica l’evento cut-off il robot viene disarmato automaticamente, e non si può armare se non spegnendo e riaccendendo FAC)
➔ Cut-off detection time: se la tensione della batteria rimane al di sotto della Cut-off voltage per questo tempo, la FAC va in cut-off, ovvero il robot viene disarmato automaticamente.
➔ Battery calibration: permette di calibrare manualmente la tensione letta dalla scheda. In pratica il valore inserito viene aggiunto alla tensione letta dalla scheda. Non modificare questa impostazione se non sai esattamente cosa stai facendo, potrebbe alterare pesantemente il comportamento della FAC!

## Receiver (ricevitore)

➔ Receiver type: permette di scegliere il tipo di ricevitore che si sta usando. Si può scegliere tra diversi tipi:

◆ PWM, fino a 4 canali;
◆ PPM, fino a 8 canali;
◆ ELRS, non ancora implementato;
◆ NRF24, non ancora implementato.


Ad esempio, se si utilizza una ricevente FS2A montata direttamente al di sopra della FAC, con la ricevente in modalità PWM (modalità di default) si deve selezionare PWM. La stessa cosa si applica per le altre modalità.

➔ Channels deadzone percentage: permette di impostare una zona morta (deadzone) nei canali del sistema radio per mitigare il possibile non centraggio perfetto degli stick del radiocomando. La zona morta è espressa in percentuale rispetto al range (dal 2% al 5% dovrebbe essere sufficiente).
➔ Arming channel: si può utilizzare un canale letto dal ricevitore per armare e disarmare la FAC direttamente dal telecomando. Questa funzionalità si può disabilitare. Se disabilitata appena la FAC viene accesa è subito armata. Si disarma automaticamente quando in cut-off. Quando è attiva questa impostazione, è necessario selezionare il canale utilizzato per l’arming. In questo caso la FAC si arma quando il canale selezionato ha un valore superiore al 80% del suo valore massimo.

## Mappaggio

Il mappaggio serve per poter decidere dove verranno utilizzate le uscite generate dai MIX e dalle Funzioni Speciali. Ovvero ci permette di decidere se utilizzare la funzione/mix su un motore DC oppure una uscita servo.

Tutte le connessioni presenti nella FAC possono essere mappate a piacere utilizzando il Mapper presente nel lato destro del FAC tool. Sono disponibili tre uscite motori DC e due uscite servo.

Ogni connessione può essere mappata ad una uscita generata da un MIX o Funzione Speciale. Si può mappare una uscita su più
connessioni della FAC.


Sul FAC tool è presente un’anteprima generata in base
alla configurazione scelta con il Mapper. L’anteprima rappresenta i vari collegamenti da effettuare sulla FAC per poter utilizzarla sul robot con la configurazione scelta. Premendo sull'icona della stampante si può stampare l’illustrazione con tutte le informazioni necessarie al corretto collegamento. Sotto l’anteprima si può scegliere se visualizzare un servomotore o un ESC+BLDC nelle uscite servo, questa opzione è puramente a scopo illustrativo, non modifica alcun comportamento della FAC.

## MIX e FUNZIONI SPECIALI

A seconda del firmware installato, la FAC può creare diversi segnali di controllo tramite MIX e Funzioni Speciali.
Questi segnali possono comandare movimenti, come la velocità e la direzione di un motore o la posizione di un servo.

Infine, tramite il Mapper, è possibile decidere su quali connettori fisici della FAC inviare questi segnali.

Pian piano verranno aggiunti ulteriori MIX e Funzioni Speciali (se avete delle richieste specifiche inviare una mail a thefloppylab@gmail.com).

## Special Functions (Funzioni Speciali)

Una Funzione Speciale genera un'uscita (soltanto una), mappabile con il Mapper, che permette di aggiungere comportamenti (automatizzati o non) alle connessioni fisiche della FAC.

Le seguenti sono le Funzioni speciali attivabili:

➔ DC Servo: (non ancora implementata) permette di creare un servomotore con un motore DC collegato sulle uscite M1/M2/M3, controllando la posizione tramite l’ingresso analogico A.AUX collegato ad un potenziometro. Il controllo viene effettuato tramite un controllo PID. La posizione del DC servo viene impostata dal canale del radiocomando selezionato.
➔ Direct link to channel: questa funzione speciale è estremamente utile per il controllo diretto di servomotori ed ESC, ma anche di motori DC. Quello che fa è prendere il segnale del canale scelto e generare l’uscita secondo la logica qui sotto riportata in base ai casi di utilizzo. Si
possono attivare fino a otto funzioni “direct link to
channel”.


La logica è leggermente diversa in base alla connessione selezionata sul Mapper:
◆ motori DC: decidere direzione e velocità direttamente proporzionale al valore del canale selezionato. Dove il valore centrale del canale è motore fermo, fino ad arrivare al massimo e minimo che corrispondono rispettivamente a velocità massima in avanti, e velocità massima indietro. (la direzione del motore può essere invertita nelle impostazioni Motors & Servos)


◆ servo: decidere l’angolo di posizione del servo.
◆ ESC: decidere la velocità del motore brushless collegato all’ESC (anche direzione con la stessa logica del motore DC nel caso in cui l’ESC sia bidirezionale).

## MIX

I MIX servono per decidere la logica di movimento. Solitamente generano due o più uscite selezionabili con il Mapper sulle connessioni fisiche della FAC.

I seguenti sono i MIX attualmente selezionabili:

➔ None: nessun MIX attivo. Non fa nulla.

➔ Simple Tank: questo MIX serve per calcolare velocità e direzione dei motori di un robot che utilizza soltanto due ruote/cigoli (sterzo differenziale), ovvero segue la logica di movimento dei cingoli di un carro armato. Questo mix genera quindi due uscite: motore destro, motore sinistro [Left Motor, Right Motor], assegnabili poi con il Mapper. Una volta attivato si può decidere quale canale del radiocomando associare a sterzo (Steering) e acceleratore (Throttle). In più è possibile decidere se invertire o meno questi due canali, in base alle proprie esigenze.

## Servo e Motori

Queste impostazioni sono relative alla modifica del comportamento delle uscite dei motori DC e delle uscite servo.

Sulla FAC V2 sono presenti due uscite servo, dove si possono collegare servomotori e ESC (Electronic Speed Controller) per motori brushless o brushed. Poi ci sono tre uscite per motori brushed (DC).

Le uscite dei motori DC sono controllate in PWM per poter variare la velocità del motore.

Le uscite servo, mettono a disposizione il classico segale accettato dai servomotori.

Queste due categorie di uscite godono di diverse impostazioni.

## Motori

➔ Motors PWM frequency: si può scegliere la frequenza di controllo dei motori DC. Si può scegliere una frequenza il cui valore va da 100Hz a 10’000Hz. Questo può essere utile per calibrazione specifica in base ai motori usati. Per i classici N20 una frequenza di 1000/2000 Hz è sufficiente.
➔ Reverse: ogni uscita DC può essere invertita attivando l’impostazione reverse. Se viene attivata il motore girerà al contrario rispetto al valore calcolato dai MIX o Funzioni Speciali.
➔ Braking: ad ogni uscita DC si può attivare o disattivare il freno motore. Il freno motore permette di bloccare quasi istantaneamente i motori una volta impostata la velocità a zero. Il freno aiuta anche ad avere un controllo maggiore della velocità di rotazione del motore stesso. Se disattivato il motore gira anche per inerzia quando si vuole abbassare la velocità, avendo così un controllo meno accurato.

## Servo

➔ Servos PWM frequency: si può scegliere la frequenza del segnale servo generato. Alcuni servo necessitano (oppure supportano) una frequenza maggiore dei 50Hz classici. Una frequenza maggiore permette un aggiornamento dei valori maggiore. La frequenza si può scegliere da un valore minimo di 20Hz ad uno massimo di 300Hz.
➔ Reverse: ogni uscita servo può essere invertita attivando l’impostazione reverse. Se viene attivata, il servo invertirà la posizione zero con quella massima. Prestare molta attenzione a questa impostazione se viene collegato un ESC con motore a queste uscite. Il motore potrebbe partire al massimo della sua velocità, oppure l’ESC potrebbe anche non attivarsi ed entrare nelle impostazioni se non correttamente configurata. Solitamente si lascia invariato se i canali del radiocomando non sono stati invertiti.
➔ Min μs value: ad ogni servo con questa impostazione si può definire la larghezza minima dell’impulso del segnale servo generato. Alcuni servomotori (soprattutto quelli più economici) richiedono una durata dell’impulso diversa da quella standard (1ms - 2ms), con questa impostazione si può definire la larghezza minima dell’impulso generato. Il valore può essere impostato da un minimo di 100μs ad un massimo di 1499μs.
➔ Max μs value: ad ogni servo con questa impostazione si può definire la larghezza massima dell’impulso del segnale servo generato. Alcuni servomotori (soprattutto quelli più economici) richiedono una durata dell’impulso diversa da quella standard (1ms to 2ms), con questa impostazione si può definire la larghezza massima dell’impulso generato. Il valore può essere impostato da un minimo di 1501μs ad un massimo di 2900μs.

# Esempio configurazione robot


Come esempio pratico usiamo il robot Bretèllator che è provvisto di un’arma cinetica rotante e due ruote per un sistema di movimento differenziale.

Assumiamo di avere quindi:

- due ruote laterali collegate a due N20
- un'arma cinetica rotante collegata ad un motore BLDC (brushless) controllato da un ESC
- un ricevitore FS2A in modalità PWM (modalità di default) collegato alla FAC (4 canali disponibili).

Scegliamo di collegare il motore della ruota destra sulla connessione M1 e il motore della ruota sinistra sulla connessione M3. Infine l’ESC che fa andare il motore dell’arma sulla connessione servo 1.

### 1. Blocchiamo l’arma con il dispositivo di bloccaggio e solleviamo il robot

così da non far toccare le ruote.

### 2. Accendiamo il radiocomando e lo appoggiamo in un posto dove non si può

urtare e modificare la posizione degli stick.

### 3. Una volta collegata la FAC al PC con un cavo USB, mantenendo anche la

batteria collegata e l’interruttore acceso, avviamo il FAC tool.

### 4. Ricordati che la FAC non si disarma finché il ricevitore non fornisce un

segnale valido, ovvero quando il radiocomando è acceso e correttamente collegato. Quando è accesa verrà riprodotta la suoneria dai motori DC collegati.

### 5. Premiamo “Connect” e selezioniamo il dispositivo FAC_V2 e premiamo

connetti. Il FAC tool ora carica le impostazioni della FAC e poi ti permette di impostare il tutto. In alto a destra si può controllare la versione del firmware installata sulla nostra FAC.


### 6. Come prima cosa impostiamo il corretto tipo di ricevitore, quindi nel

nostro caso andiamo nella tab “General” e sotto il riquadro “Receiver”

selezioniamo PWM come tipo.


7. Non avendo molti canali con una FS2A in modalità PWM (soltanto quattro), disattiviamo l’opzione “Arming channel”. Così facendo la FAC si armerà in automatico appena accesa, quindi dobbiamo fare molta attenzione a non muovere accidentalmente i comandi del radiocomando.


8. Ora premiamo sul pulsante “Test & Save” e poi attiviamo la telemetria. Ora possiamo controllare che i primi quattro canali (CH.1-4) seguano la posizione degli stick del telecomando. Se il telecomando ha già il centro impostato correttamente, ma con gli stick sono al centro il valore visualizzato non è 500 oppure quando sono al massimo non è 999 oppure 0, dobbiamo aumentare la percentuale della deadzone. Facciamo questo finché i valori non sono accettabili. Non è necessario sistemare la deadzone, solitamente è sufficiente usare un valore tra il 2% e il 5%.


### 9. Ora nella tab “Mix & SP.Functions” andremo ad impostare il mix per le

ruote e la funzione speciale per l’arma. Quindi attiviamo il “Simple Tank” e poi selezioniamo i canali che vogliamo usare per acceleratore “Throttle” e sterzo “Steering”. Se abbiamo il radiocomando in Stick Mode 2, abbiamo come acceleratore il canale 2, e come sterzo il canale 1. La funzione speciale che ci permette di controllare direttamente l’ESC con lo stick senza molla del radiocomando (ovvero il canale 3) è un “Direct link to channel”. Quindi attiviamo il primo premendo su “Enable” e

scegliamo il canale 3.


10.Ora che abbiamo generato le uscite possiamo assegnarle alle connessioni fisiche della FAC. A sinistra dell’interfaccia abbiamo l’anteprima (Preview) e il Mapper. All’interno del mapper possiamo associare le uscite delle Funzioni Speciali e dei Mix alle connessioni reali della FAC. Ricordando i requisiti avevamo: M1 motore destro, M3 motore sinistro e servo 1 collegato all’ESC del motore brushless. Quindi sul menu a tendina di M1 selezioniamo motore destro (Motor right), sul M3 selezioniamo motore sinistro (Motor left), infine su S1 “Direct Link 1”, quelli non usati vanno impostati su “Disabled”. Sull’anteprima dovrebbero essersi aggiornati i collegamenti. Per scegliere di visualizzare al posto del servo un ESC con motore, possiamo selezionare sul menu a tendina in basso “ESC 1” (questi due menu impostano soltanto la grafica, null'altro).

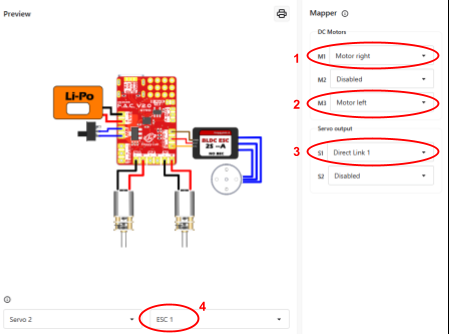
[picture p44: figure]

11.Ora come prima, premiamo su “Test & Save” e se i motori girano tutti correttamente possiamo premere “Save to FAC”, altrimenti se i motori non girano correttamente possiamo nella tab “Servos & Motors” invertire la rotazione premendo su l’opzione “Reverse” del motore desiderato e poi testiamo nuovamente le impostazioni. Consiglio di attivare il breaking sui motori DC utilizzati, così da avere un maggiore controllo della loro velocità.
12.Ora avete la FAC impostata correttamente e pronta per combattere all’interno del vostro robot!

# Domande e risposte (Q & A)

## Firmware 2.0.7 e successivi

Q. Ho impostato correttamente i canali del Tank Mix e i motori sul Mapper, ma quando cerco di andare avanti il robot gira su se stesso. Devo invertire i canali dello sterzo e acceleratore?
A. Se sei certo di aver selezionato correttamente i canali dello sterzo e dell'acceleratore il problema è che uno dei motori delle ruote sta girando al contrario. Inverti uno dei due nella tab “Servos & Motors” e dovresti aver risolto.
Q. Non riesco a disarmare la FAC, perché?
A. Controlla di aver collegato correttamente il radiocomando, questo succede perché la FAC non sta ricevendo dei segnali validi dal ricevitore, quindi quest'ultimo può essere disconnesso.

## Firmware 2.0.5 e precedenti

Q. Il FAC tool è bloccato dopo la connessione, non legge i dati dalla FAC. La FAC è rotta?
A. No, la FAC non è rotta. Per sicurezza la FAC non si attiva finché non legge dei valori validi dal ricevitore, quindi se il radiocomando è spento la FAC non si accende. Accendi il radiocomando e assicurati che il ricevitore sia collegato ad esso. La FAC dovrebbe emettere una canzone dai motori DC e poi il FAC tool leggerà i dati.

# Informazioni sul documento

Questo manuale è stato redatto da Floppy Lab™ per fornire informazioni sull’utilizzo e le funzionalità della FAC.

Tutti i file del progetti si possono trovare all’indirizzo: https://github.com/FloppyO1/Floppy-Ant-Controller

Per modifiche, suggerimenti o feedback, scrivere a: thefoppylab@gmail.com.

Seguici anche sui nostri canali social:

- Instagram: the_floppy_lab (https://www.instagram.com/the_floppy_lab/)
- YouTube: @floppylab (https://www.youtube.com/@floppylab)
- GitHub: FloppyO1 (https://github.com/FloppyO1)
- Sito: www.floppylab.it

Grazie per il tuo supporto e per aver scelto i progetti del Floppy Lab!

Questo progetto è rilasciato secondo i termini della licenza inclusa nel repository ufficiale. Si invita a consultare il file LICENSE su GitHub (https://github.com/FloppyO1/Floppy-Ant-Controller) per verificare i diritti di utilizzo e ridistribuzione.

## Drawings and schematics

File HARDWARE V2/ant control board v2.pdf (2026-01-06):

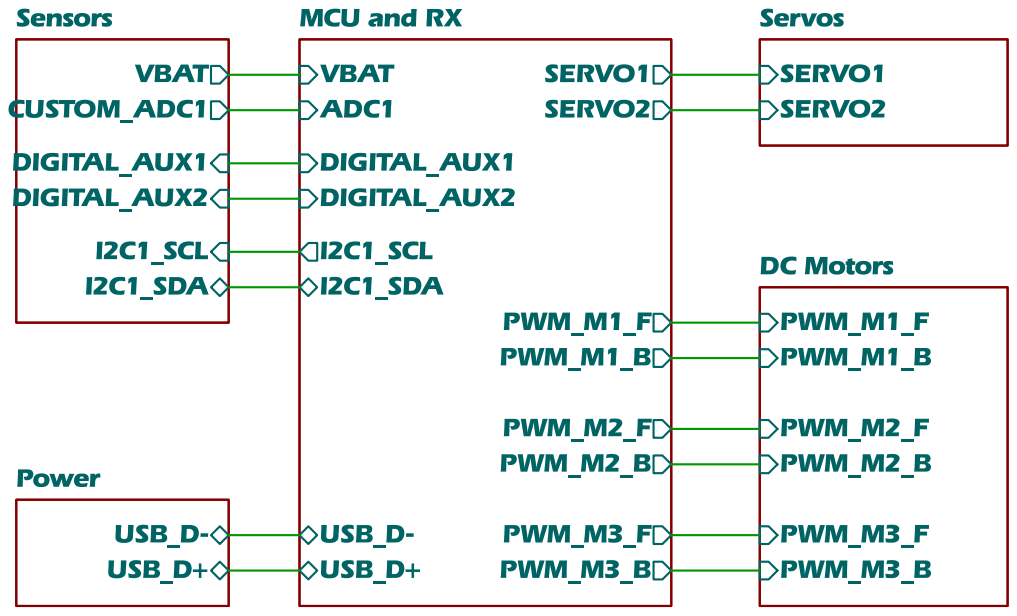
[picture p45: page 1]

Id: 1/6 Title: Ant Robot control board

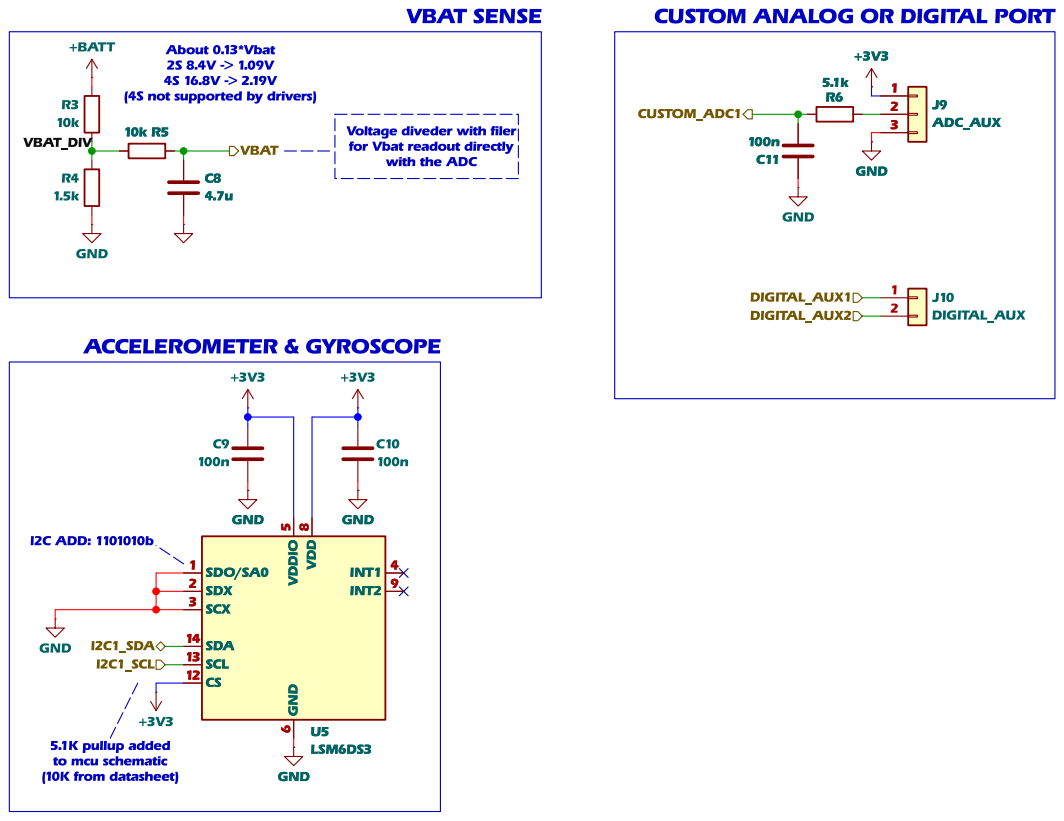
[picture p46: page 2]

(4S not supported by drivers)
for Vbat readout directly with the ADC ACCELEROMETER & GYROSCOPE

Voltage diveder with filer

Id: 5/6 Title: Ant Robot control board

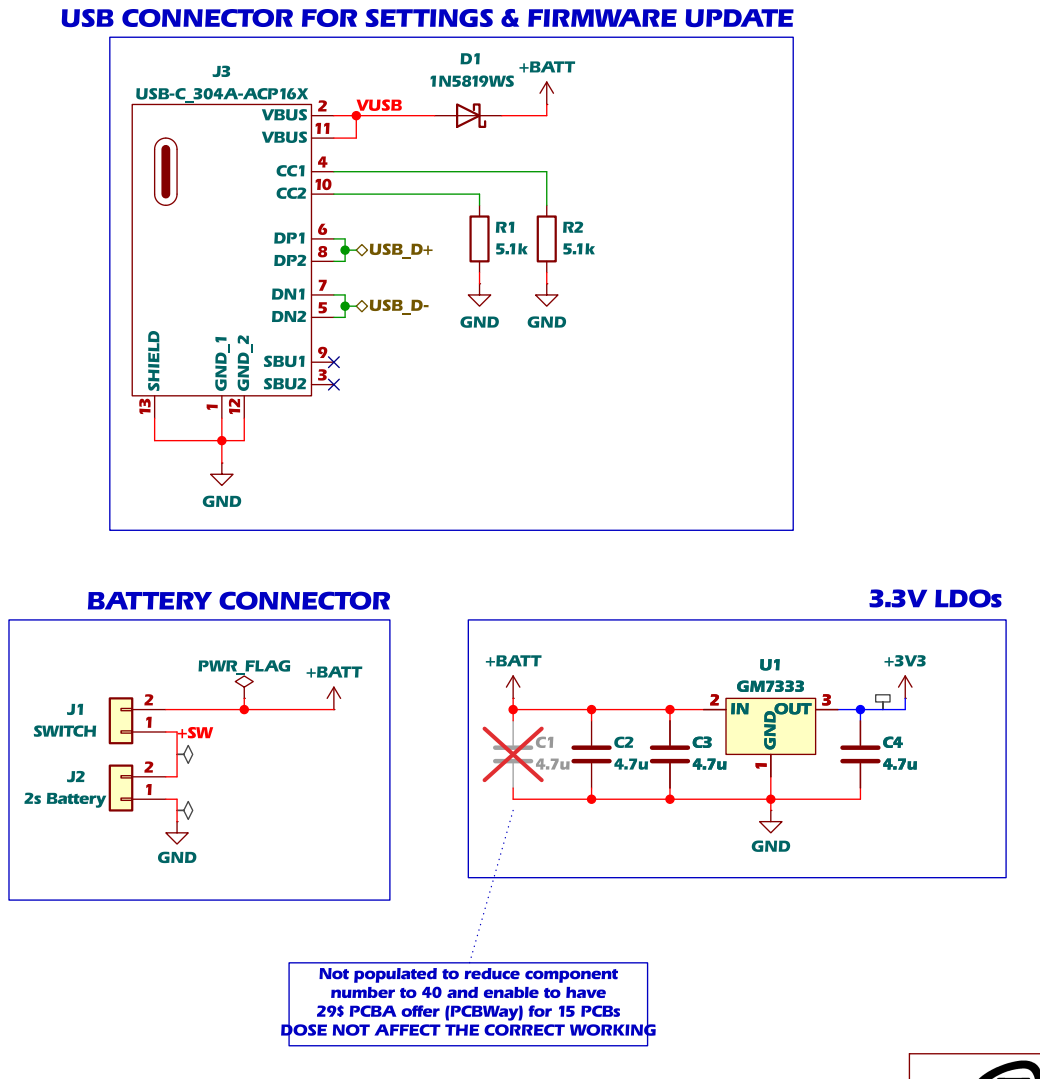
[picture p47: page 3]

USB CONNECTOR FOR SETTINGS & FIRMWARE UPDATE
J3 USB-C_304A-ACP16X GND

Not populated to reduce component number to 40 and enable to have

Id: 2/6 Title: Ant Robot control board

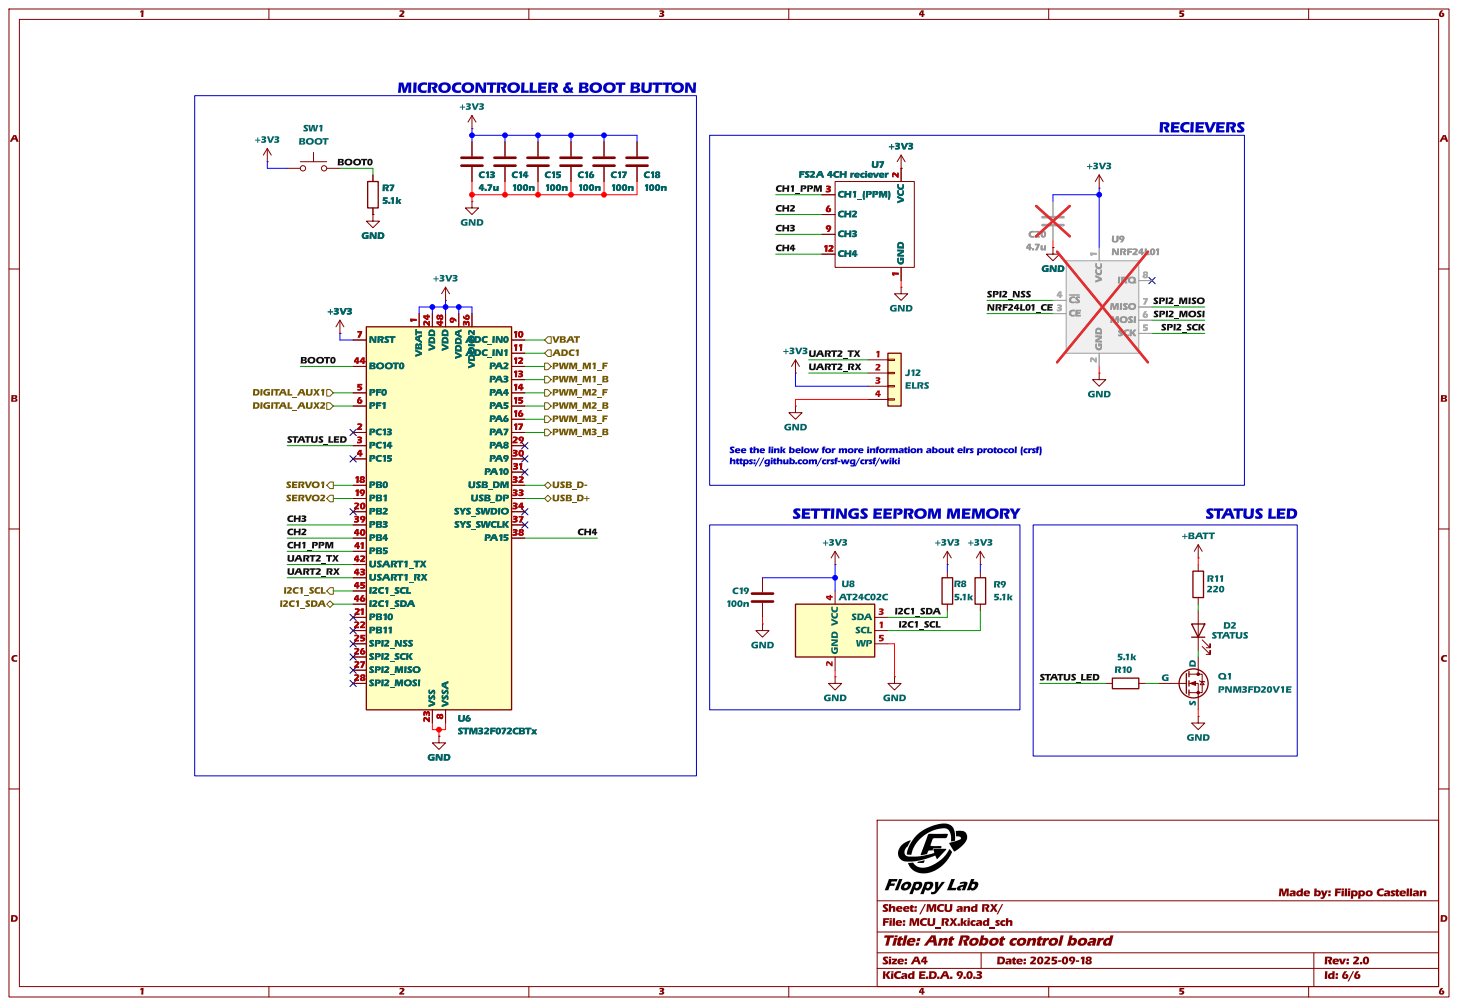
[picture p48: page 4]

1 VDD 24 VSS 23 VDD 48 VSSA

https://github.com/crsf-wg/crsf/wiki

Id: 6/6 Title: Ant Robot control board

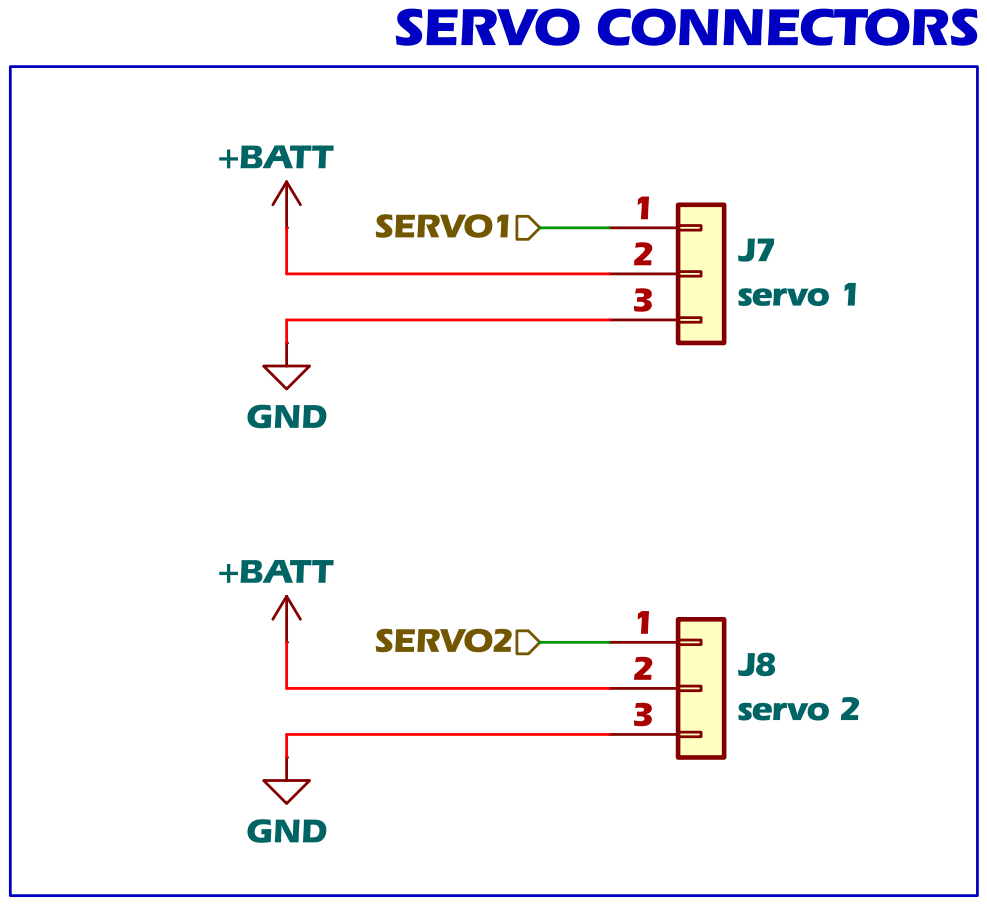
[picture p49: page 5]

Id: 4/6 Title: Ant Robot control board

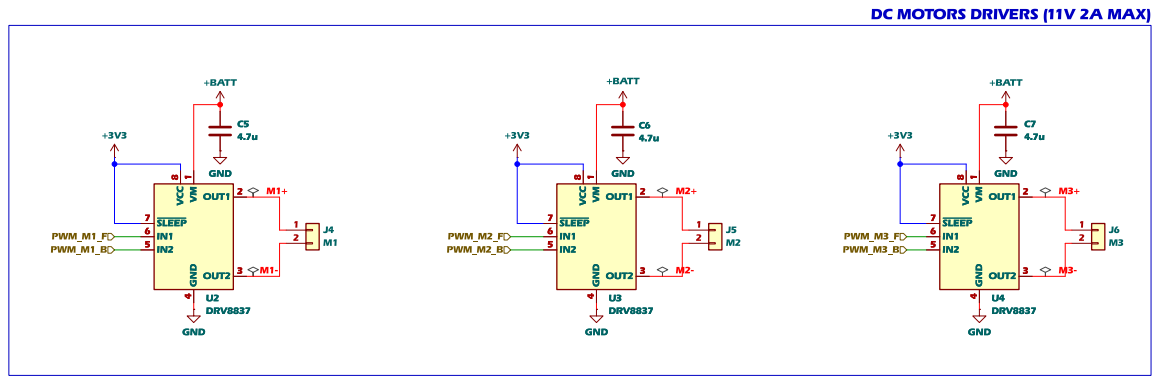
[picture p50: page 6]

Id: 3/6 Title: Ant Robot control board

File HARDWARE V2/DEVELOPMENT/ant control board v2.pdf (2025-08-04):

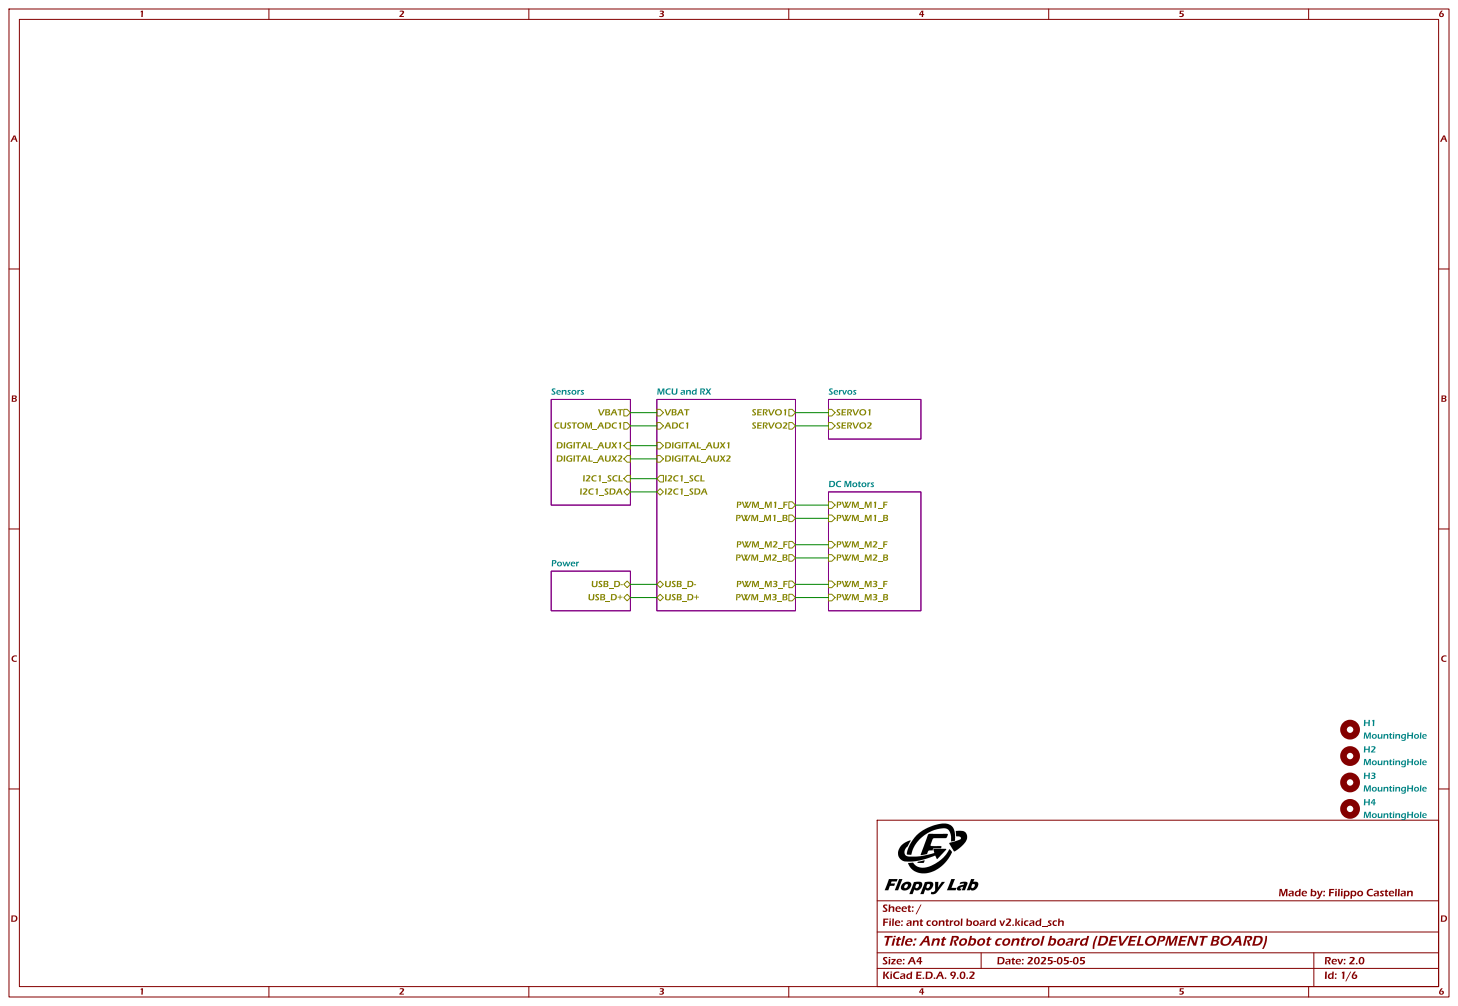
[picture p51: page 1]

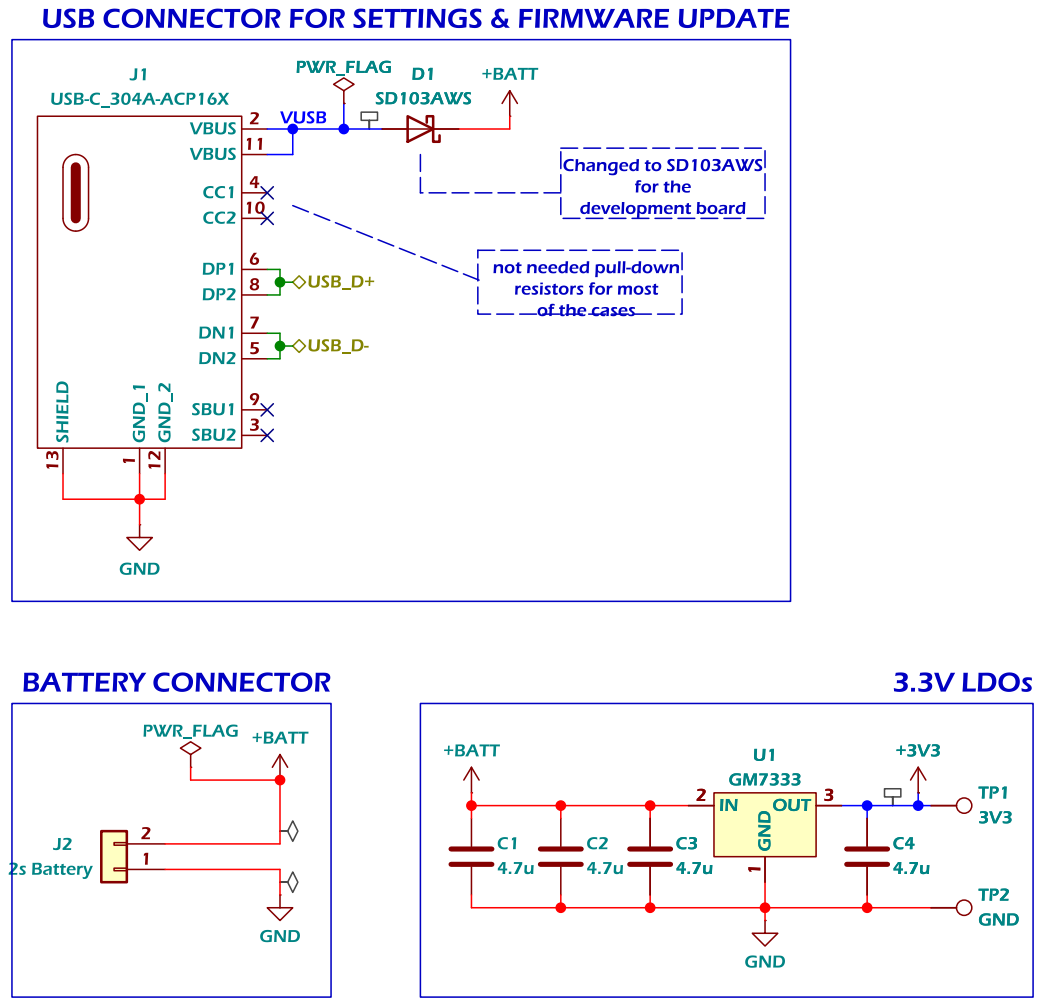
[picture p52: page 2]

USBCONNECTOR FOR SETTINGS& FIRMWARE UPDATE
USB_D+ USB_D- VUSB
development board C3

not needed pull-down

Id: 2/6 Title: Ant Robot control board

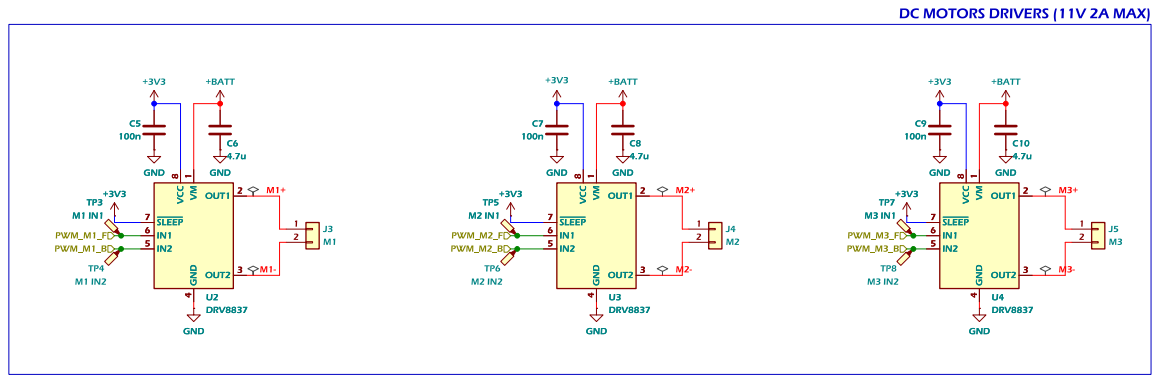
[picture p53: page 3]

Id: 3/6 Title: Ant Robot control board

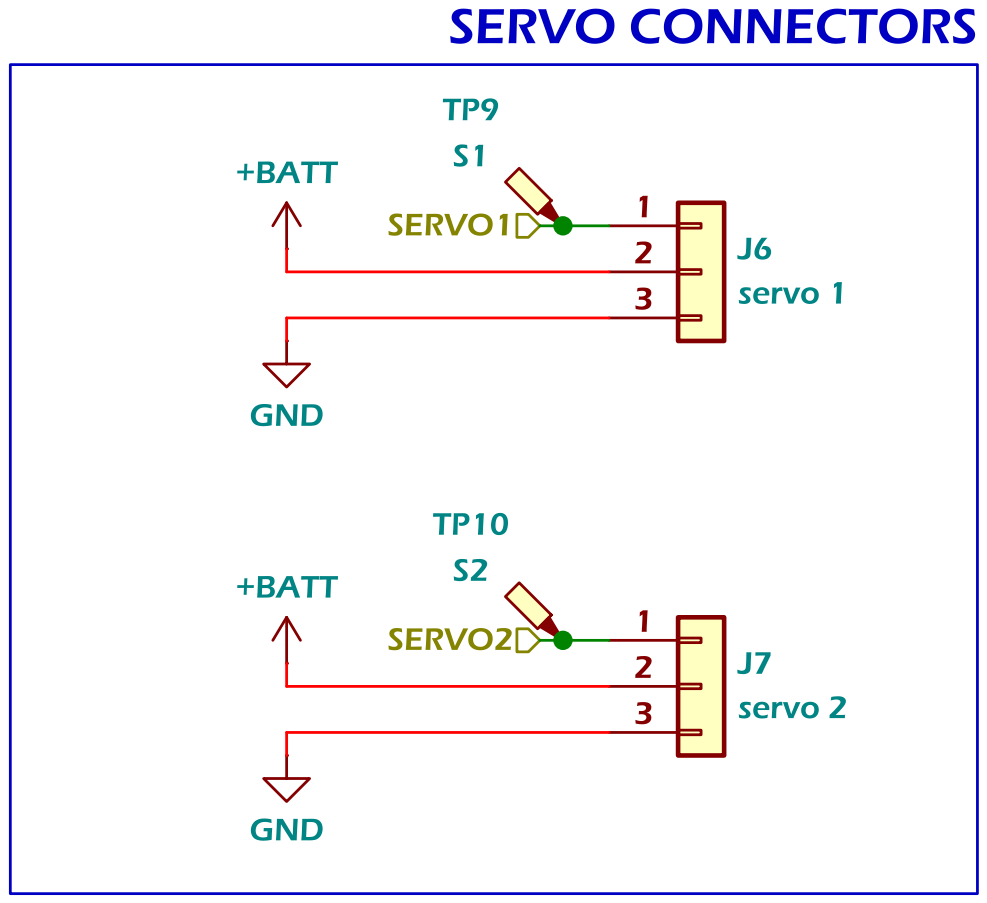
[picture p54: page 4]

Id: 4/6 Title: Ant Robot control board

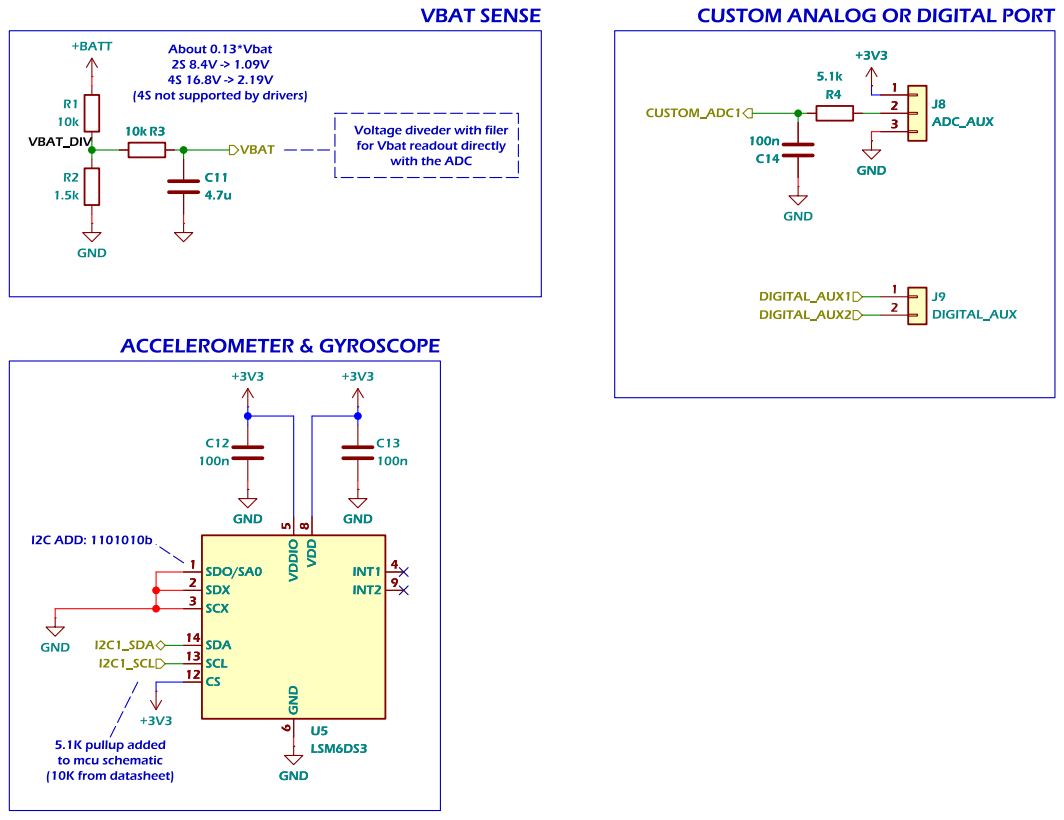
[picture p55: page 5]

Voltage diveder with filer

Id: 5/6 Title: Ant Robot control board

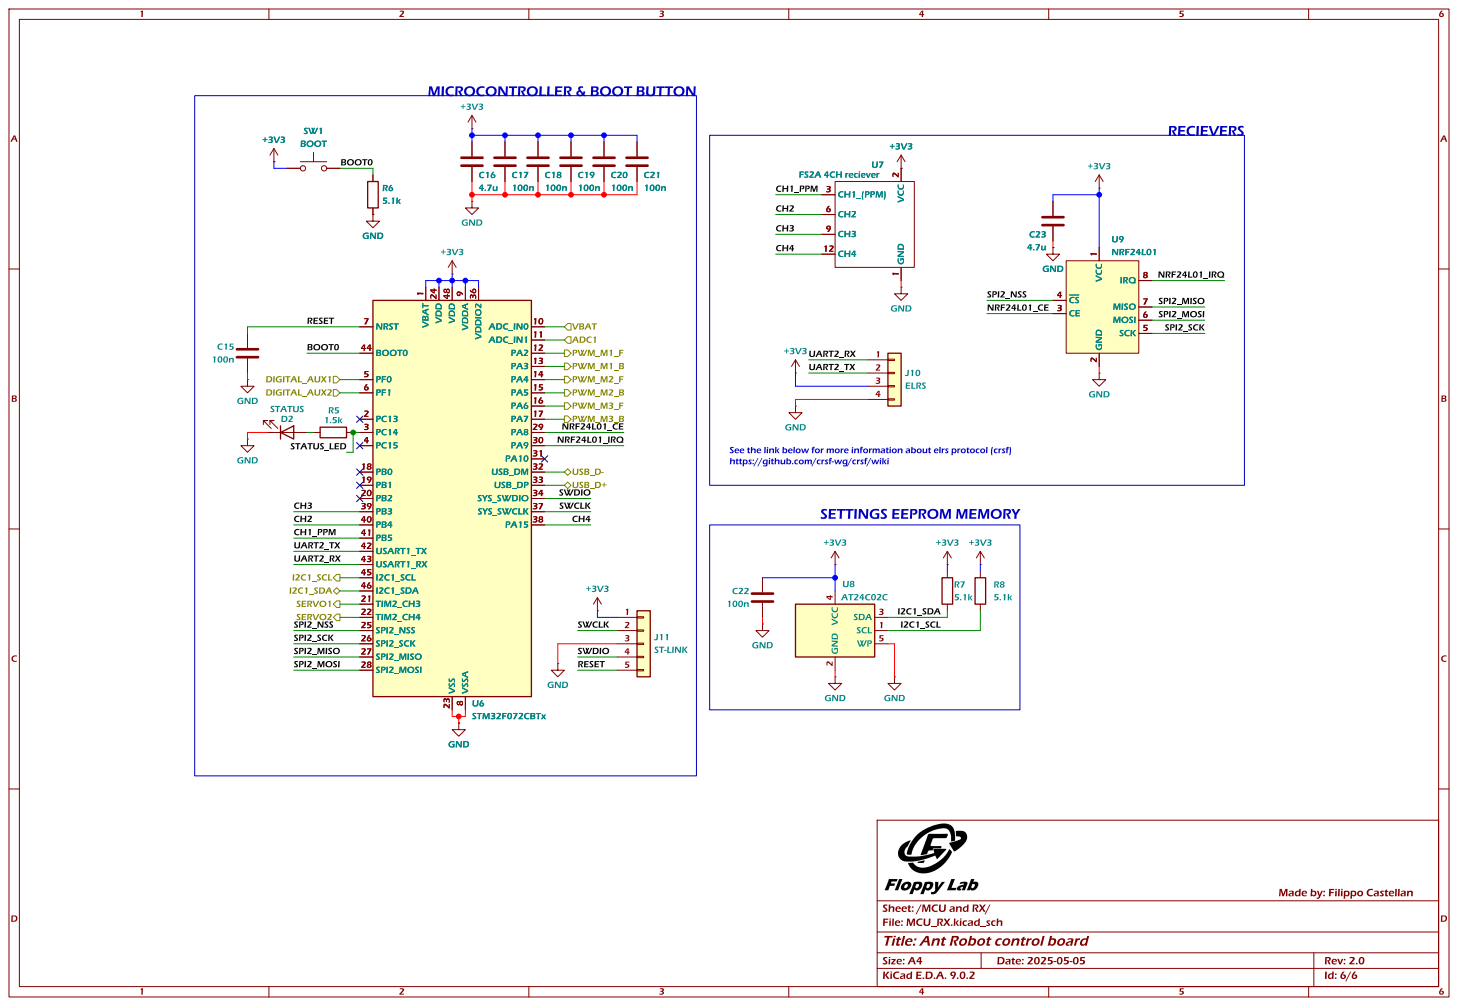
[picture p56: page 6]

1 VDD 24 VDD 48 VSS 23 VDDA

https://github.com/crsf-wg/crsf/wiki

Id: 6/6 Title: Ant Robot control board

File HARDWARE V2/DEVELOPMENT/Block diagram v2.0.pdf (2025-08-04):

BATTERY; 3V3 LDO; MCU STM32F072CB/C8 64KB/128KB FLASH; FILTERING CAP; RECIEVER FS2A; DRV8837; POT x1; SERVO OUT x2; VBAT SENSE; LED; GYRO/ACCEL LSM6DS3












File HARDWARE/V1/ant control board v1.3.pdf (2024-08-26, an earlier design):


2 CH1_(PPM) 3 CH2 6 CH3 9 U4 FS2A 4CH reciever mount SW2 RESET C16

TO USE1SBATTERY
SHORTALL 3 CONNECTIONs
(for 1Susage, the buck
converter is not needed)

for Vbat readout directly with the ADC

File: ant control board v1.3.kicad_sch Sheet: / C7

Id: 1/1 Title: Ant Robot control board

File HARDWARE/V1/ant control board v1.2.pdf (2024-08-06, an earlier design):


for Vbat readout directly with the ADC

converter is not needed) BUCKCONVERTER

File: ant control board v1.2.kicad_sch Sheet: /
Id: 1/1 Title: Ant Robot control board

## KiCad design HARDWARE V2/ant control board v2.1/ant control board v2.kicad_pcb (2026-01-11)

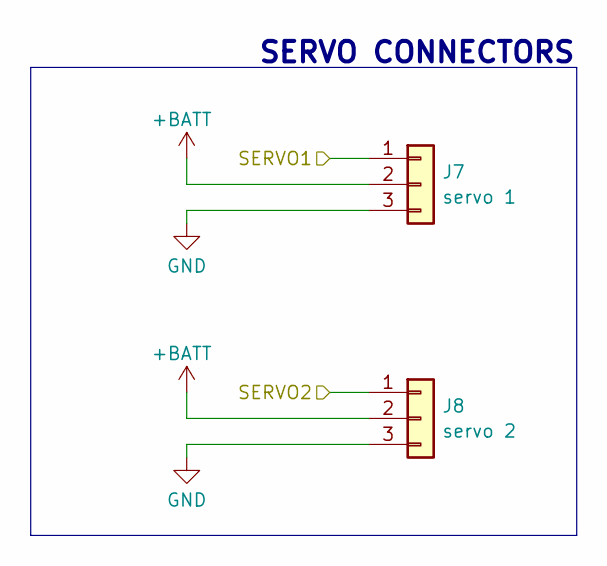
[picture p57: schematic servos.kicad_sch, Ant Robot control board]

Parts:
J7: servo 1; 01x03_TH_pad_renforced
J8: servo 2; 01x03_TH_pad_renforced

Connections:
+BATT: J7.2, J8.2; also elsewhere on the board
/MCU and RX/SERVO1: J7.1; also elsewhere on the board
/MCU and RX/SERVO2: J8.1; also elsewhere on the board
GND: J7.3, J8.3; also elsewhere on the board

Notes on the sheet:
SERVO CONNECTORS

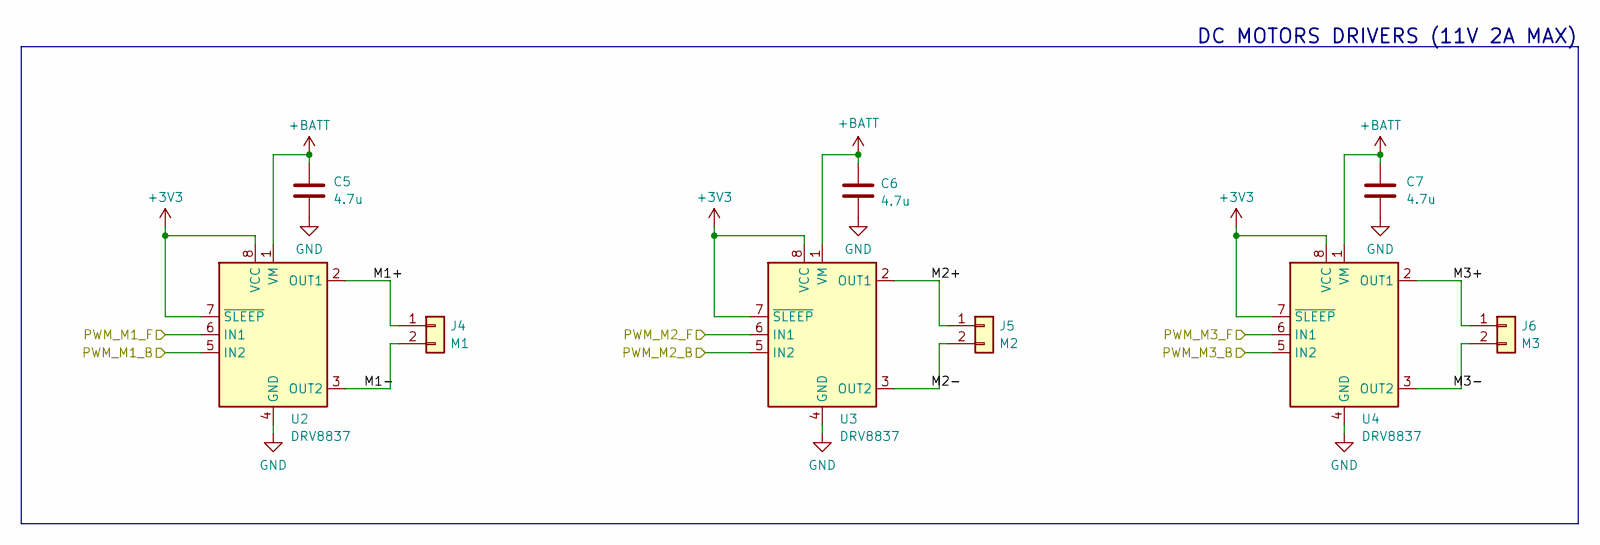
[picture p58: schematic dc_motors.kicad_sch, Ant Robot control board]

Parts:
C5, C6, C7: 4.7u; C_0402_1005Metric; LCSC C2858031
J4: M1; 01x02_TH_pad_renforced
J5: M2; 01x02_TH_pad_renforced
J6: M3; 01x02_TH_pad_renforced
U2, U3, U4: DRV8837; WSON-8-1EP_2x2mm_P0.5mm_EP0.9x1.6mm; LCSC C39159

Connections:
+3V3: U2.7 (~SLEEP), U2.8 (VCC), U3.7 (~SLEEP), U3.8 (VCC), U4.7 (~SLEEP), U4.8 (VCC); also elsewhere on the board
+BATT: C5.1, C6.1, C7.1, U2.1 (VM), U3.1 (VM), U4.1 (VM); also elsewhere on the board
/DC Motors/M1+: J4.1, U2.2 (OUT1)
/DC Motors/M1-: J4.2, U2.3 (OUT2)
/DC Motors/M2+: J5.1, U3.2 (OUT1)
/DC Motors/M2-: J5.2, U3.3 (OUT2)
/DC Motors/M3+: J6.1, U4.2 (OUT1)
/DC Motors/M3-: J6.2, U4.3 (OUT2)
/DC Motors/PWM_M1_B: U2.5 (IN2); also elsewhere on the board
/DC Motors/PWM_M1_F: U2.6 (IN1); also elsewhere on the board
/DC Motors/PWM_M2_B: U3.5 (IN2); also elsewhere on the board
/DC Motors/PWM_M2_F: U3.6 (IN1); also elsewhere on the board
/DC Motors/PWM_M3_B: U4.5 (IN2); also elsewhere on the board
/DC Motors/PWM_M3_F: U4.6 (IN1); also elsewhere on the board
GND: C5.2, C6.2, C7.2, U2.4 (GND), U2.9 (GND), U3.4 (GND), U3.9 (GND), U4.4 (GND), U4.9 (GND); also elsewhere on the board

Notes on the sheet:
DC MOTORS DRIVERS (11V 2A MAX)

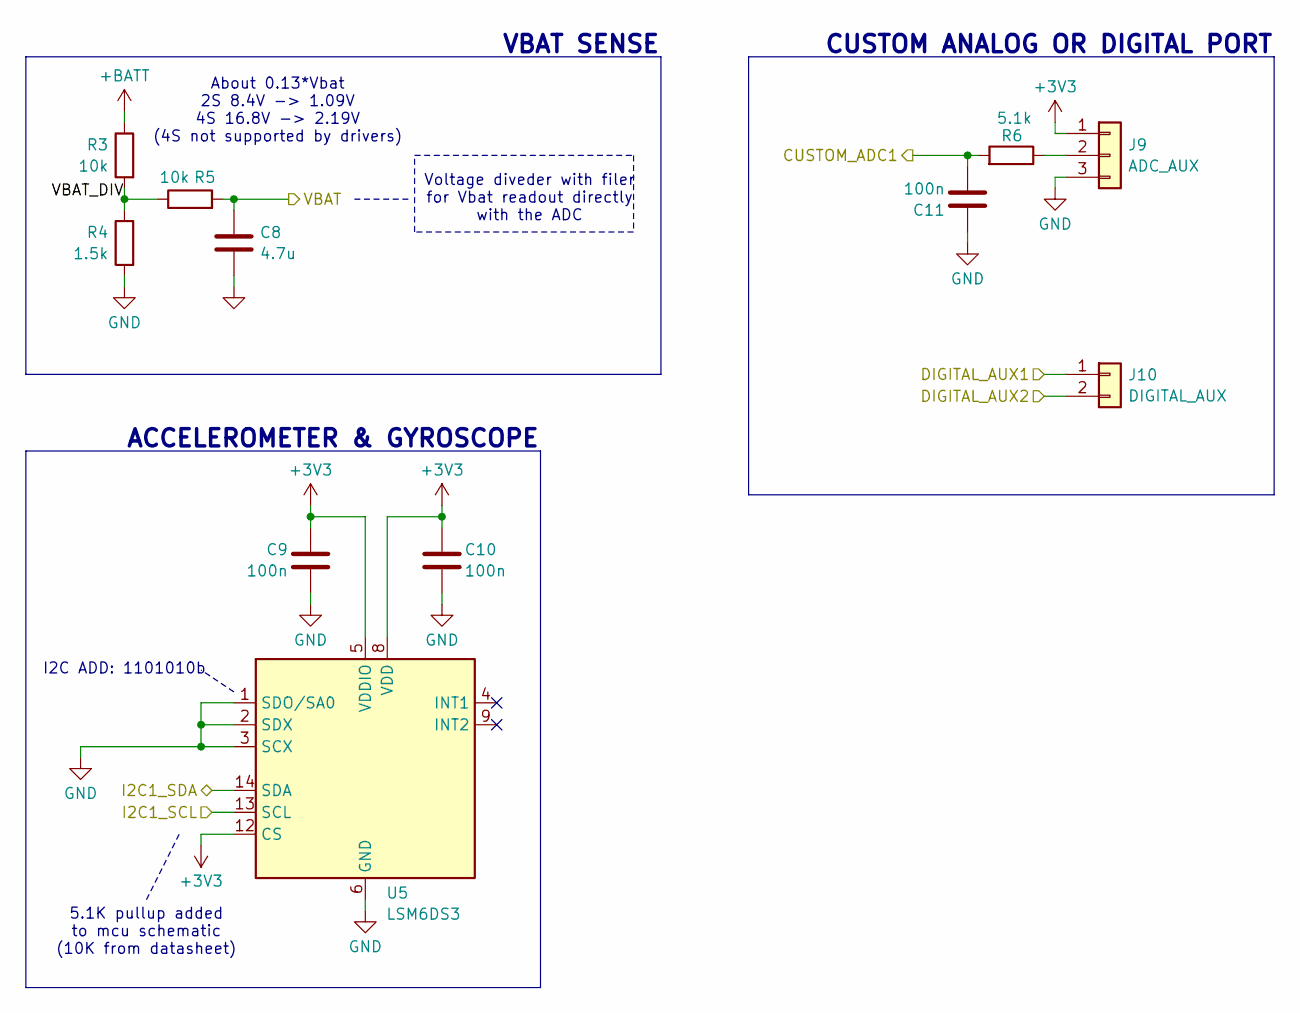
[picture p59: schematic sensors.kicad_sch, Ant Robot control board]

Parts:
C8: 4.7u; C_0402_1005Metric; LCSC C2858031
C9, C10, C11: 100n; C_0402_1005Metric; LCSC C1525
J9: ADC_AUX; 01x03_TH_pad_renforced_small
J10: DIGITAL_AUX; 01x02_TH_pad_renforced_small
R3, R5: 10k; R_0402_1005Metric; LCSC C60490
R4: 1.5k; R_0402_1005Metric; LCSC C25867
R6: 5.1k; R_0402_1005Metric; LCSC C25905
U5: LSM6DS3; LGA-14_3x2.5mm_P0.5mm_LayoutBorder3x4y; LCSC C967633

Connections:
+3V3: C9.1, C10.1, J9.1, U5.5 (VDDIO), U5.8 (VDD), U5.12 (CS); also elsewhere on the board
+BATT: R3.1; also elsewhere on the board
/MCU and RX/ADC1: C11.2, R6.2; also elsewhere on the board
/MCU and RX/DIGITAL_AUX1: J10.1; also elsewhere on the board
/MCU and RX/DIGITAL_AUX2: J10.2; also elsewhere on the board
/MCU and RX/I2C1_SCL: U5.13 (SCL); also elsewhere on the board
/MCU and RX/I2C1_SDA: U5.14 (SDA); also elsewhere on the board
/MCU and RX/VBAT: C8.2, R5.2; also elsewhere on the board
/Sensors/VBAT_DIV: R3.2, R4.1, R5.1
GND: C8.1, C9.2, C10.2, C11.1, J9.3, R4.2, U5.1 (SDO/SA0), U5.2 (SDX), U5.3 (SCX), U5.6 (GND), U5.7 (GND); also elsewhere on the board
unnamed: J9.2, R6.1

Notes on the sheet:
VBAT SENSE
About 0.13*Vbat 2S 8.4V -> 1.09V 4S 16.8V -> 2.19V (4S not supported by drivers)
Voltage diveder with filer for Vbat readout directly with the ADC
CUSTOM ANALOG OR DIGITAL PORT
ACCELEROMETER & GYROSCOPE
5.1K pullup added to mcu schematic (10K from datasheet)
I2C ADD: 1101010b

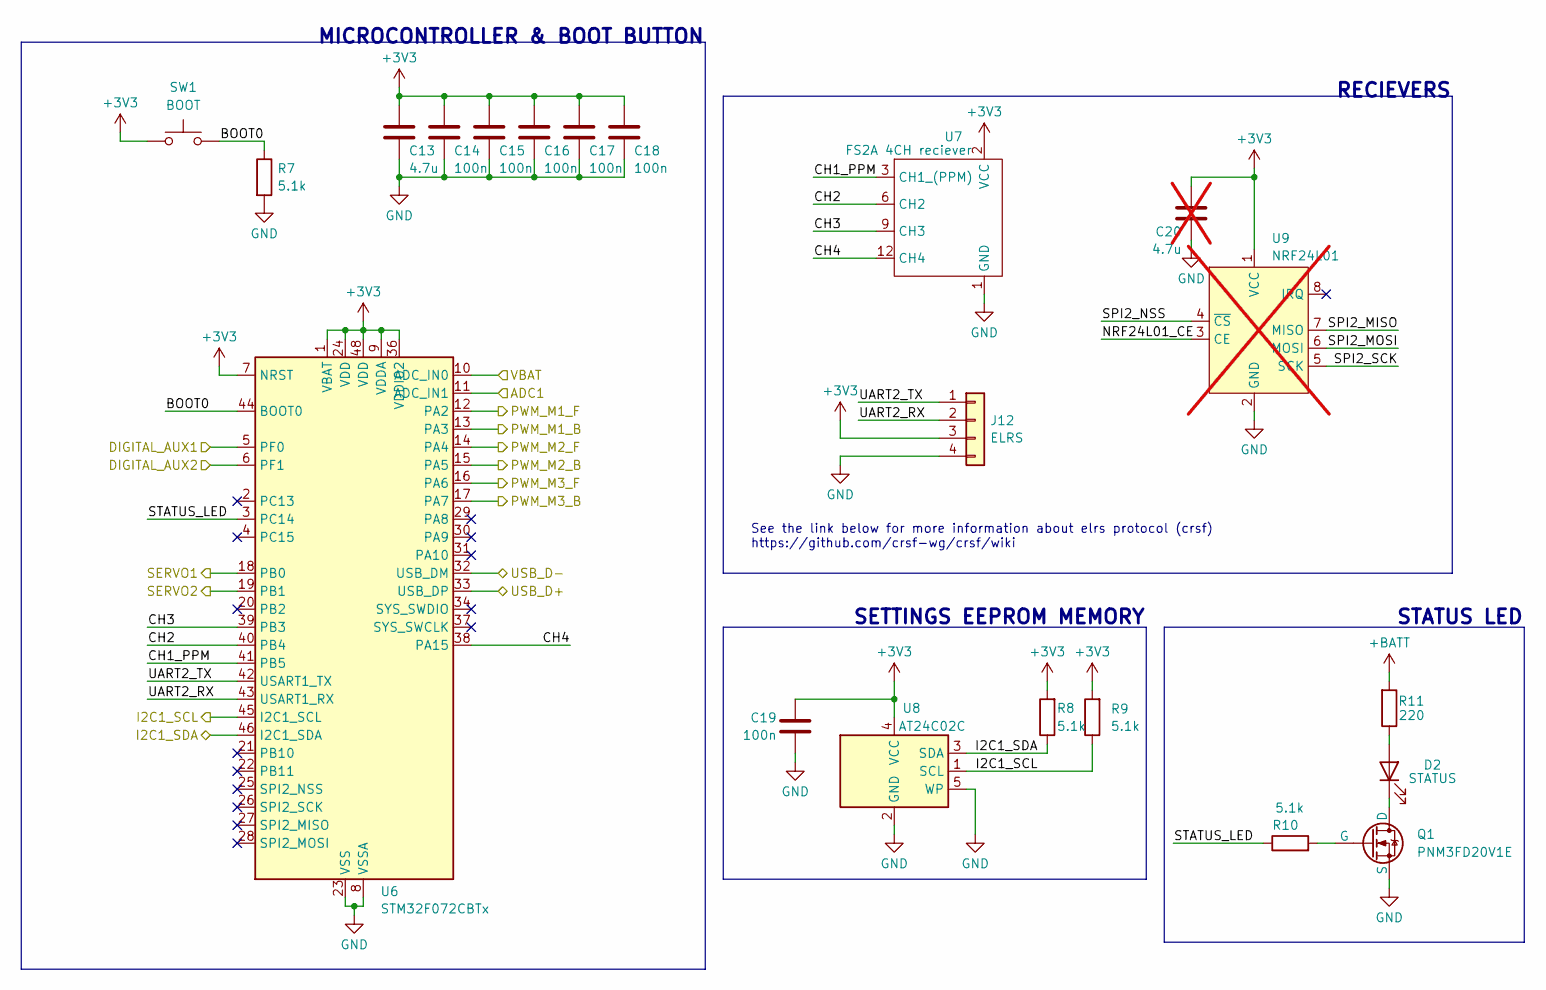
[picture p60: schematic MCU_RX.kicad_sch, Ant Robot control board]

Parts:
C13: 4.7u; C_0402_1005Metric; LCSC C2858031
C14, C15, C16, C17, C18, C19: 100n; C_0402_1005Metric; LCSC C1525
C20: 4.7u; C_0402_1005Metric; LCSC C2858031; not fitted
D2: STATUS; LED_1206_3216Metric; LCSC C779809
J12: ELRS; Pad 01x04 small
Q1: PNM3FD20V1E; Diodes_DFN1006-3; LCSC C2875806
R7, R8, R9, R10: 5.1k; R_0402_1005Metric; LCSC C25905
R11: 220; R_0402_1005Metric; LCSC C112291
SW1: BOOT; SW_SPST_B3U-1000P; LCSC C2885149
U6: STM32F072CBTx; LQFP-48_7x7mm_P0.5mm; LCSC C81720
U7: FS2A 4CH reciever
U8: AT24C02C; SOT-23-5; LCSC C7432363
U9: NRF24L01; NRF24L01+ SMD; not fitted

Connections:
+3V3: C13.1, C14.1, C15.1, C16.1, C17.1, C18.1, C19.1, C20.1, J12.3, R8.2, R9.2, SW1.1, U6.1 (VBAT), U6.7 (NRST), U6.9 (VDDA), U6.24 (VDD), U6.36 (VDDIO2), U6.48 (VDD), U7.2 (VCC), U7.5, U7.8, U7.11, U8.4 (VCC), U9.1 (VCC); also elsewhere on the board
+BATT: R11.2; also elsewhere on the board
/DC Motors/PWM_M1_B: U6.13 (PA3); also elsewhere on the board
/DC Motors/PWM_M1_F: U6.12 (PA2); also elsewhere on the board
/DC Motors/PWM_M2_B: U6.15 (PA5); also elsewhere on the board
/DC Motors/PWM_M2_F: U6.14 (PA4); also elsewhere on the board
/DC Motors/PWM_M3_B: U6.17 (PA7); also elsewhere on the board
/DC Motors/PWM_M3_F: U6.16 (PA6); also elsewhere on the board
/MCU and RX/ADC1: U6.11 (ADC_IN1); also elsewhere on the board
/MCU and RX/BOOT0: R7.1, SW1.2, U6.44 (BOOT0)
/MCU and RX/CH1_PPM: U6.41 (PB5), U7.3 (CH1_(PPM))
/MCU and RX/CH2: U6.40 (PB4), U7.6 (CH2)
/MCU and RX/CH3: U6.39 (PB3), U7.9 (CH3)
/MCU and RX/CH4: U6.38 (PA15), U7.12 (CH4)
/MCU and RX/DIGITAL_AUX1: U6.5 (PF0); also elsewhere on the board
/MCU and RX/DIGITAL_AUX2: U6.6 (PF1); also elsewhere on the board
/MCU and RX/I2C1_SCL: R9.1, U6.45 (I2C1_SCL), U8.1 (SCL); also elsewhere on the board
/MCU and RX/I2C1_SDA: R8.1, U6.46 (I2C1_SDA), U8.3 (SDA); also elsewhere on the board
/MCU and RX/SERVO1: U6.18 (PB0); also elsewhere on the board
/MCU and RX/SERVO2: U6.19 (PB1); also elsewhere on the board
/MCU and RX/STATUS_LED: R10.1, U6.3 (PC14)
/MCU and RX/UART2_RX: J12.2, U6.43 (USART1_RX)
/MCU and RX/UART2_TX: J12.1, U6.42 (USART1_TX)
/MCU and RX/USB_D+: U6.33 (USB_DP); also elsewhere on the board
/MCU and RX/USB_D-: U6.32 (USB_DM); also elsewhere on the board
/MCU and RX/VBAT: U6.10 (ADC_IN0); also elsewhere on the board
GND: C13.2, C14.2, C15.2, C16.2, C17.2, C18.2, C19.2, C20.2, J12.4, Q1.2 (S), R7.2, U6.8 (VSSA), U6.23 (VSS), U6.35 (VSS), U6.47 (VSS), U7.1 (GND), U7.4, U7.7, U7.10, U8.2 (GND), U8.5 (WP), U9.2 (GND); also elsewhere on the board
unnamed: D2.2 (A), R11.1
unnamed: D2.1 (K), Q1.3 (D)
unnamed: Q1.1 (G), R10.2

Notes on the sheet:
RECIEVERS
SETTINGS EEPROM MEMORY
See the link below for more information about elrs protocol (crsf) https://github.com/crsf-wg/crsf/wiki
STATUS LED
MICROCONTROLLER & BOOT BUTTON

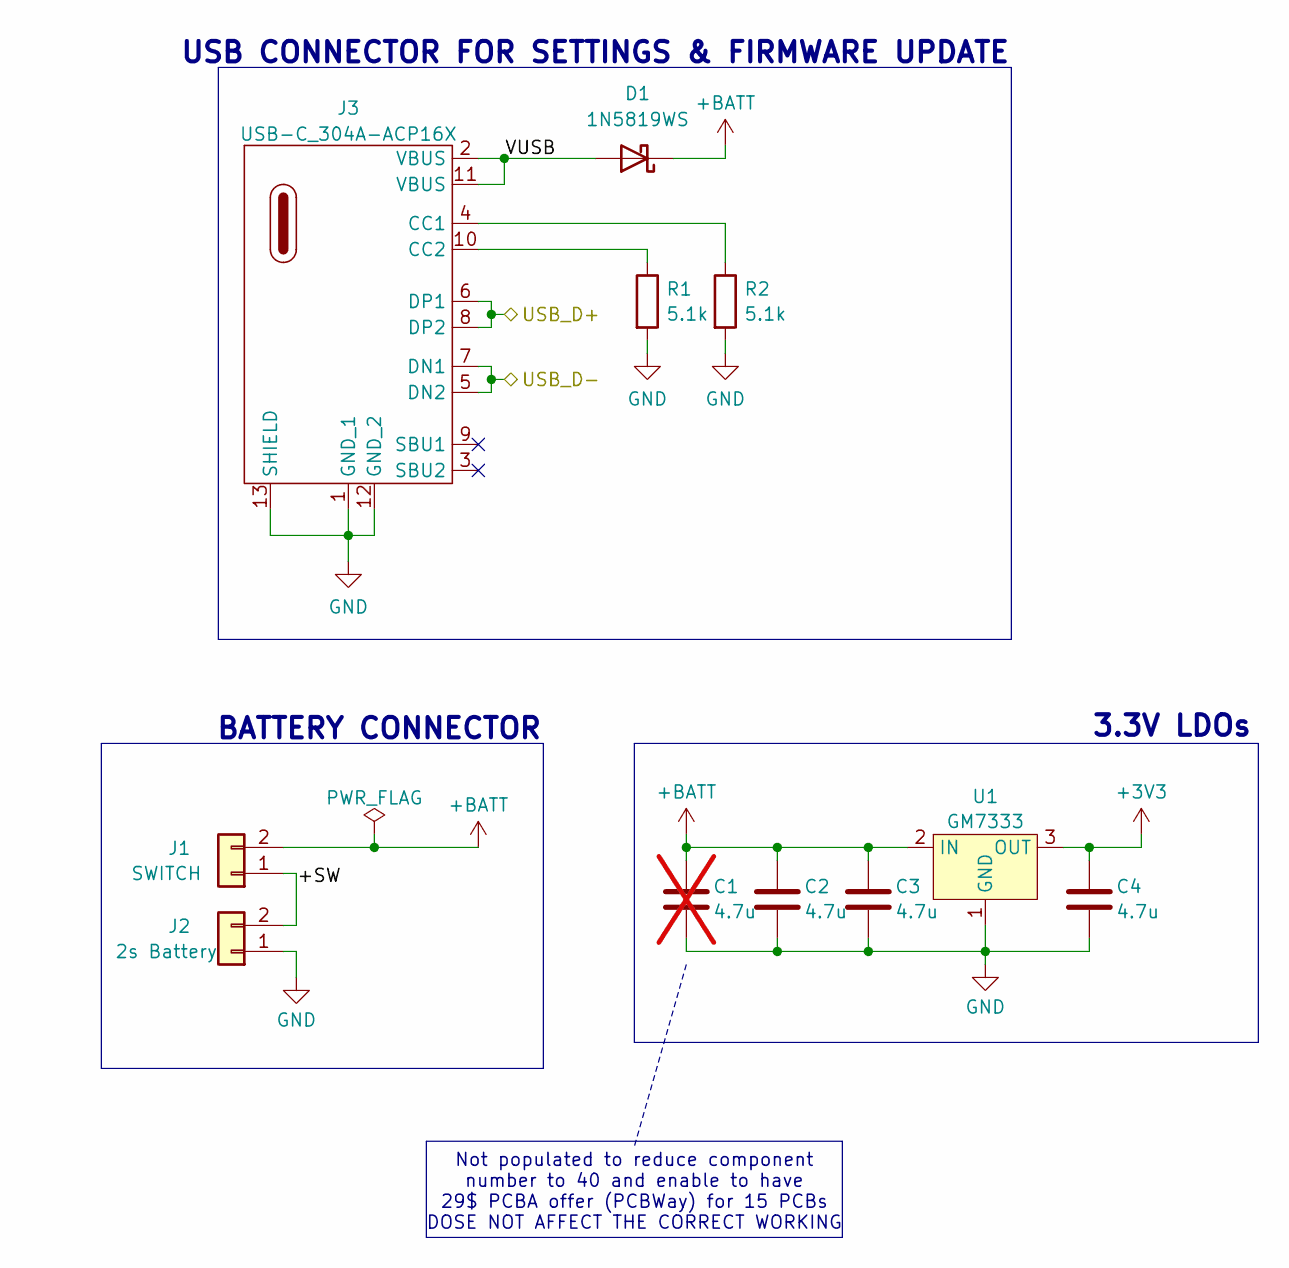
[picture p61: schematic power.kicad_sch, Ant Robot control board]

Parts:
C1: 4.7u; C_0402_1005Metric; VOLTAGE 25V; LCSC C2858031; not fitted
C2, C3: 4.7u; C_0402_1005Metric; VOLTAGE 25V; LCSC C2858031
C4: 4.7u; C_0402_1005Metric; LCSC C2858031
D1: 1N5819WS; D_SOD-323; LCSC C191023
J1: SWITCH; 01x02_TH_pad_renforced
J2: 2s Battery; 01x02_TH_pad_renforced
J3: USB-C_304A-ACP16X; USB_C_304A-ACP16X; LCSC C2909609
R1, R2: 5.1k; R_0402_1005Metric; LCSC C25905
U1: GM7333; SOT-89-3; LCSC C2833582

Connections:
+3V3: C4.1, U1.3 (OUT); also elsewhere on the board
+BATT: C1.1, C2.1, C3.1, D1.1 (K), J1.2, U1.2 (IN); also elsewhere on the board
/MCU and RX/USB_D+: J3.6 (DP1), J3.8 (DP2); also elsewhere on the board
/MCU and RX/USB_D-: J3.5 (DN2), J3.7 (DN1); also elsewhere on the board
/Power/+SW: J1.1, J2.2
/Power/VUSB: D1.2 (A), J3.2 (VBUS), J3.11 (VBUS)
GND: C1.2, C2.2, C3.2, C4.2, J2.1, J3.1 (GND_1), J3.12 (GND_2), J3.13 (SHIELD), R1.2, R2.2, U1.1 (GND); also elsewhere on the board
unnamed: J3.4 (CC1), R2.1
unnamed: J3.10 (CC2), R1.1

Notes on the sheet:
BATTERY CONNECTOR
3.3V LDOs
USB CONNECTOR FOR SETTINGS & FIRMWARE UPDATE
Not populated to reduce component number to 40 and enable to have 29$ PCBA offer (PCBWay) for 15 PCBs DOSE NOT AFFECT THE CORRECT WORKING

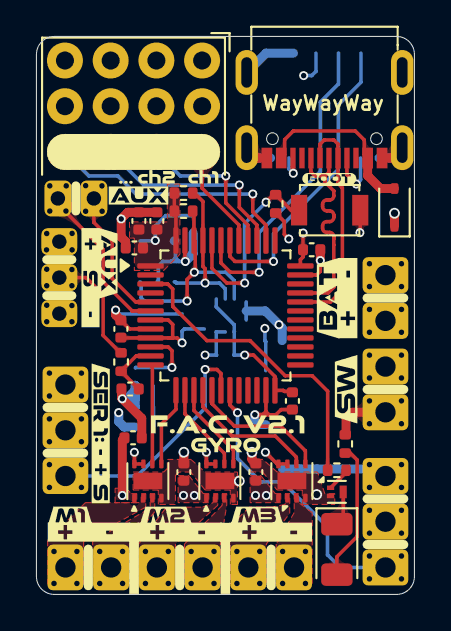
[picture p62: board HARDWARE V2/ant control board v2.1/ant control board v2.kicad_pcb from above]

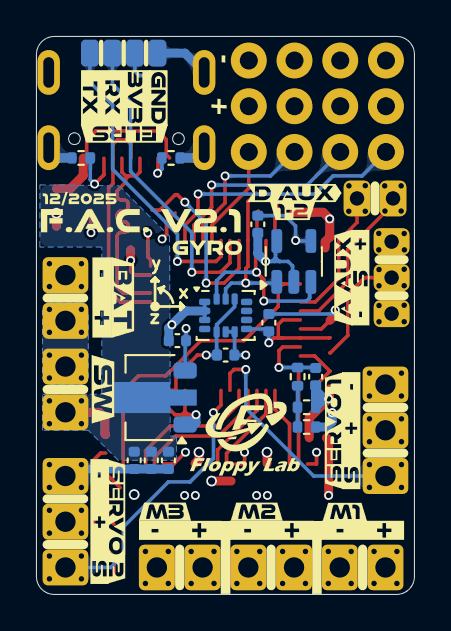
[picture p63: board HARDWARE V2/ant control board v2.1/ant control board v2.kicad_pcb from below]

Board: 4 copper layers, 21.0 x 31.0 mm, 98 parts (44 on the bottom side), 42 nets.

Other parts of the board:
kibuzzard-68CD6E18, kibuzzard-68CD6E18#2: G***; kibuzzard-68CD6E18
kibuzzard-68CD6E40: G***; kibuzzard-68CD6E40
kibuzzard-68CD6E53, kibuzzard-68CD6E53#2: G***; kibuzzard-68CD6E53
kibuzzard-68CD7A1F: G***; kibuzzard-68CD7A1F
kibuzzard-68CD7CD9, kibuzzard-68CD7CD9#2: G***; kibuzzard-68CD7CD9
kibuzzard-68CD71AA, kibuzzard-68CD71AA#2: G***; kibuzzard-68CD71AA
kibuzzard-68CD73CB: G***; kibuzzard-68CD73CB
kibuzzard-68CD73D1: G***; kibuzzard-68CD73D1
kibuzzard-68CD78A4: G***; kibuzzard-68CD78A4
kibuzzard-68CD78BE: G***; kibuzzard-68CD78BE
kibuzzard-68CD78F0: G***; kibuzzard-68CD78F0
kibuzzard-68CD79A4: G***; kibuzzard-68CD79A4
kibuzzard-68CD79BE: G***; kibuzzard-68CD79BE
kibuzzard-68CD717E: G***; kibuzzard-68CD717E
kibuzzard-68CD725D, kibuzzard-68CD725D#2: G***; kibuzzard-68CD725D
kibuzzard-68CD756A: G***; kibuzzard-68CD756A
kibuzzard-68CD769D: G***; kibuzzard-68CD769D
kibuzzard-68CD784B: G***; kibuzzard-68CD784B
kibuzzard-68CD787F: G***; kibuzzard-68CD787F
kibuzzard-68CD793B: G***; kibuzzard-68CD793B
kibuzzard-68CD795A: G***; kibuzzard-68CD795A
kibuzzard-68CD7254, kibuzzard-68CD7254#2: G***; kibuzzard-68CD7254
kibuzzard-68CD7457: G***; kibuzzard-68CD7457
kibuzzard-68CD7642: G***; kibuzzard-68CD7642
kibuzzard-68CFBDBE: G***; kibuzzard-68CFBDBE
kibuzzard-68CFBDCF: G***; kibuzzard-68CFBDCF
kibuzzard-68CFBDD6: G***; kibuzzard-68CFBDD6
kibuzzard-68CFBE33: G***; kibuzzard-68CFBE33
kibuzzard-68CFBFAF: G***; kibuzzard-68CFBFAF
kibuzzard-68CFBFFE: G***; kibuzzard-68CFBFFE
kibuzzard-68CFC012: G***; kibuzzard-68CFC012
kibuzzard-68CFC153: G***; kibuzzard-68CFC153
kibuzzard-68CFCF3D: G***; kibuzzard-68CFCF3D
kibuzzard-68CFCF36: G***; kibuzzard-68CFCF36
kibuzzard-68CFCF49: G***; kibuzzard-68CFCF49
kibuzzard-6935A1A7: G***; kibuzzard-6935A1A7
kibuzzard-6935A19F: G***; kibuzzard-6935A19F
kibuzzard-6935A190: G***; kibuzzard-6935A190
kibuzzard-69359CA2: G***; kibuzzard-69359CA2
kibuzzard-69359CAC: G***; kibuzzard-69359CAC

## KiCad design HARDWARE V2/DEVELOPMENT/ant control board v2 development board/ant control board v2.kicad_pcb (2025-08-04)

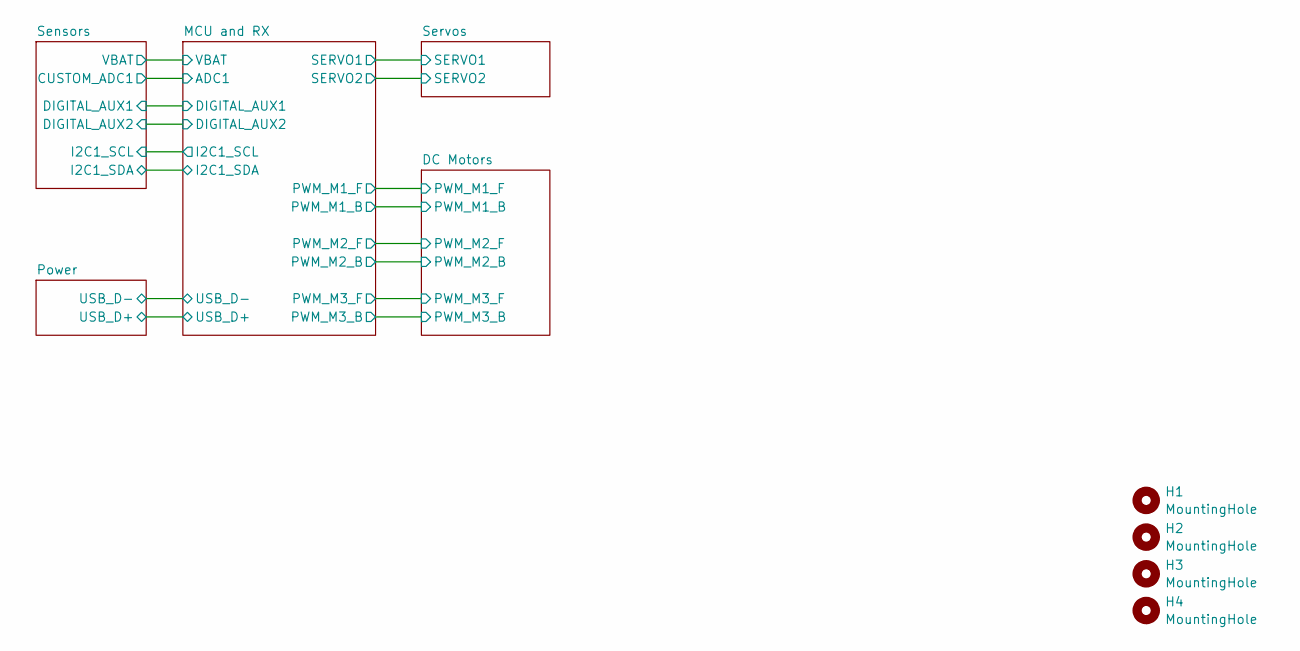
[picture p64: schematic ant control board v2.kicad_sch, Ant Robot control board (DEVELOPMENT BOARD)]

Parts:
H1, H2, H3, H4: MountingHole; MountingHole_2.2mm_M2_Pad_Via

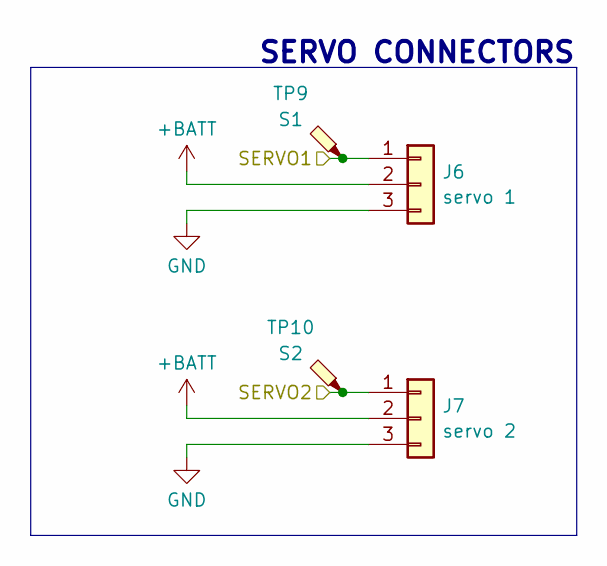
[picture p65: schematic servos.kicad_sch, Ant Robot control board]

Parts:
J6: servo 1; PinHeader_1x03_P2.54mm_Vertical
J7: servo 2; PinHeader_1x03_P2.54mm_Vertical
TP9: S1; TestPoint_THTPad_1.5x1.5mm_Drill0.7mm
TP10: S2; TestPoint_THTPad_1.5x1.5mm_Drill0.7mm

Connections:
+BATT: J6.2, J7.2; also elsewhere on the board
/MCU and RX/SERVO1: J6.1, TP9.1; also elsewhere on the board
/MCU and RX/SERVO2: J7.1, TP10.1; also elsewhere on the board
GND: J6.3, J7.3; also elsewhere on the board

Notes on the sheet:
SERVO CONNECTORS

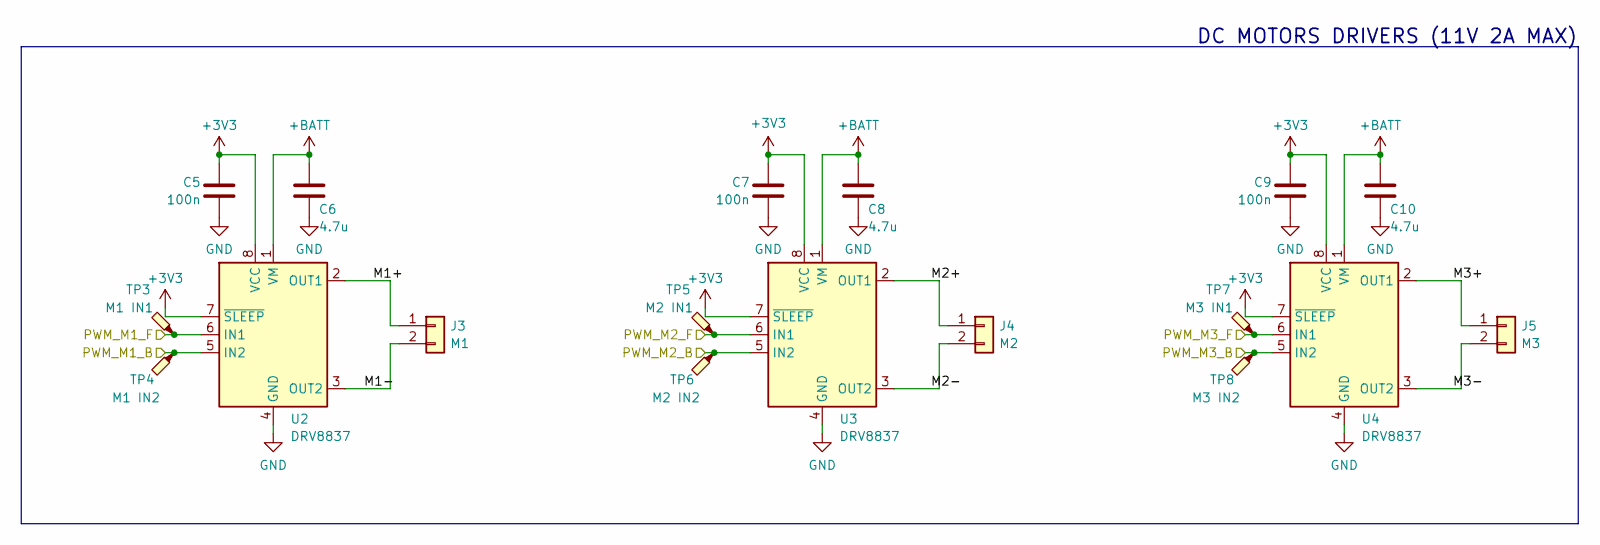
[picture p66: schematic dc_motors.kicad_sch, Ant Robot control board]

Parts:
C5, C7, C9: 100n; C_0603_1608Metric; LCSC C282519
C6, C8, C10: 4.7u; C_0603_1608Metric; LCSC C2858031
J3: M1; PinHeader_1x02_P2.54mm_Vertical
J4: M2; PinHeader_1x02_P2.54mm_Vertical
J5: M3; PinHeader_1x02_P2.54mm_Vertical
TP3: M1 IN1; TestPoint_THTPad_1.5x1.5mm_Drill0.7mm
TP4: M1 IN2; TestPoint_THTPad_1.5x1.5mm_Drill0.7mm
TP5: M2 IN1; TestPoint_THTPad_1.5x1.5mm_Drill0.7mm
TP6: M2 IN2; TestPoint_THTPad_1.5x1.5mm_Drill0.7mm
TP7: M3 IN1; TestPoint_THTPad_1.5x1.5mm_Drill0.7mm
TP8: M3 IN2; TestPoint_THTPad_1.5x1.5mm_Drill0.7mm
U2, U3, U4: DRV8837; WSON-8-1EP_2x2mm_P0.5mm_EP0.9x1.6mm; LCSC C39159

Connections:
+3V3: C5.1, C7.1, C9.1, U2.7 (~SLEEP), U2.8 (VCC), U3.7 (~SLEEP), U3.8 (VCC), U4.7 (~SLEEP), U4.8 (VCC); also elsewhere on the board
+BATT: C6.1, C8.1, C10.1, U2.1 (VM), U3.1 (VM), U4.1 (VM); also elsewhere on the board
/DC Motors/M1+: J3.1, U2.2 (OUT1)
/DC Motors/M1-: J3.2, U2.3 (OUT2)
/DC Motors/M2+: J4.1, U3.2 (OUT1)
/DC Motors/M2-: J4.2, U3.3 (OUT2)
/DC Motors/M3+: J5.1, U4.2 (OUT1)
/DC Motors/M3-: J5.2, U4.3 (OUT2)
/DC Motors/PWM_M1_B: TP4.1, U2.5 (IN2); also elsewhere on the board
/DC Motors/PWM_M1_F: TP3.1, U2.6 (IN1); also elsewhere on the board
/DC Motors/PWM_M2_B: TP6.1, U3.5 (IN2); also elsewhere on the board
/DC Motors/PWM_M2_F: TP5.1, U3.6 (IN1); also elsewhere on the board
/DC Motors/PWM_M3_B: TP8.1, U4.5 (IN2); also elsewhere on the board
/DC Motors/PWM_M3_F: TP7.1, U4.6 (IN1); also elsewhere on the board
GND: C5.2, C6.2, C7.2, C8.2, C9.2, C10.2, U2.4 (GND), U2.9 (GND), U3.4 (GND), U3.9 (GND), U4.4 (GND), U4.9 (GND); also elsewhere on the board

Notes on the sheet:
DC MOTORS DRIVERS (11V 2A MAX)

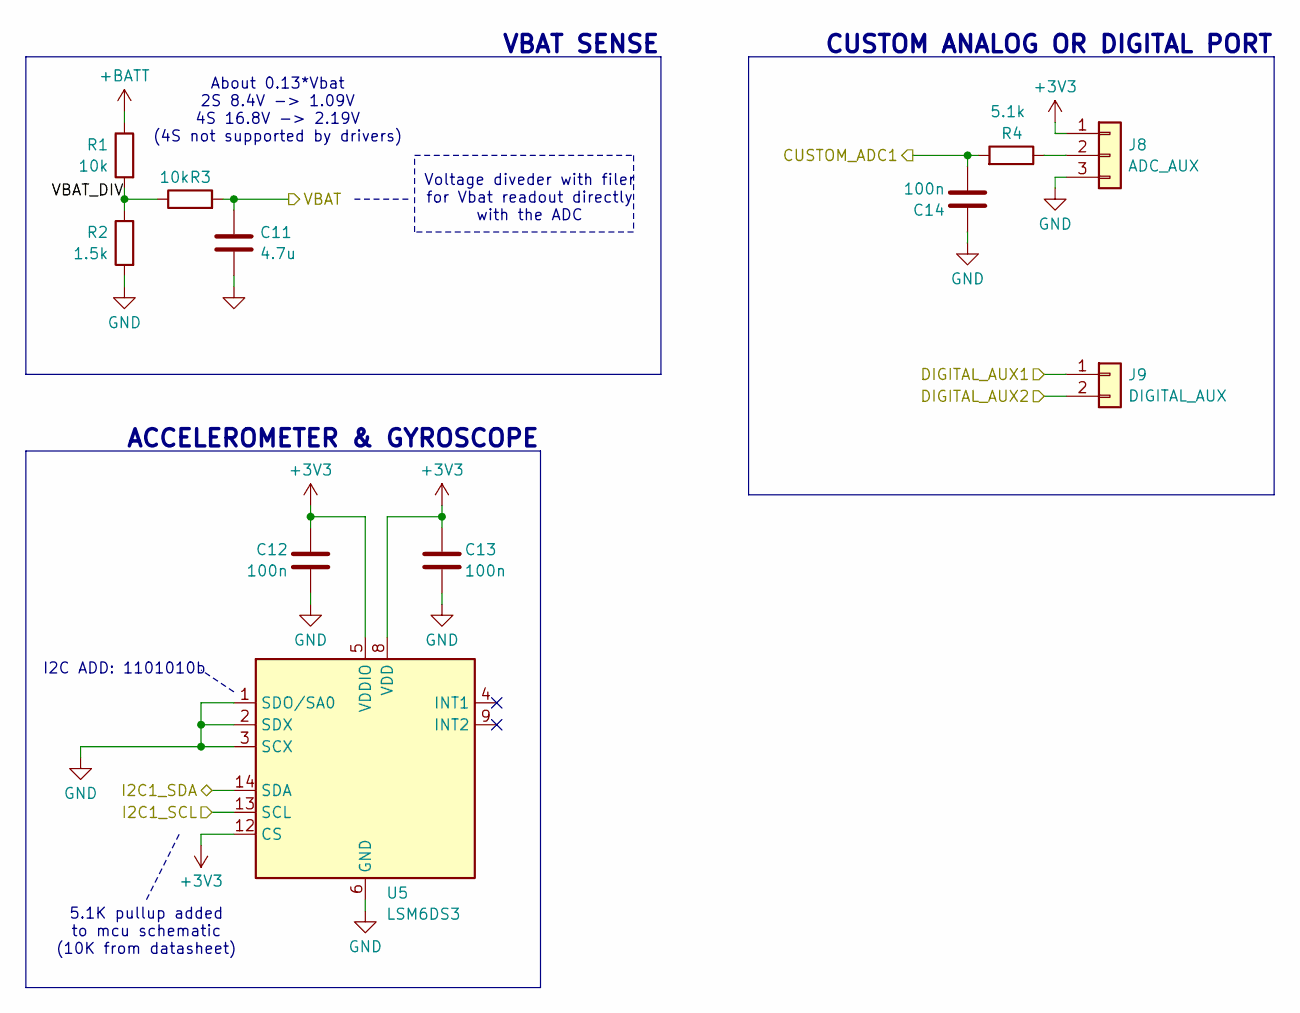
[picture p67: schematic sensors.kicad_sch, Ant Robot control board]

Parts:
C11: 4.7u; C_0603_1608Metric; LCSC C2858031
C12, C13, C14: 100n; C_0603_1608Metric; LCSC C282519
J8: ADC_AUX; PinHeader_1x03_P2.54mm_Vertical
J9: DIGITAL_AUX; PinHeader_1x02_P2.54mm_Vertical
R1, R3: 10k; R_0603_1608Metric; LCSC C103199
R2: 1.5k; R_0603_1608Metric; LCSC C114668
R4: 5.1k; R_0603_1608Metric; LCSC C23186
U5: LSM6DS3; LGA-14_3x2.5mm_P0.5mm_LayoutBorder3x4y; LCSC C967633

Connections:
+3V3: C12.1, C13.1, J8.1, U5.5 (VDDIO), U5.8 (VDD), U5.12 (CS); also elsewhere on the board
+BATT: R1.1; also elsewhere on the board
/MCU and RX/ADC1: C14.2, R4.2; also elsewhere on the board
/MCU and RX/DIGITAL_AUX1: J9.1; also elsewhere on the board
/MCU and RX/DIGITAL_AUX2: J9.2; also elsewhere on the board
/MCU and RX/I2C1_SCL: U5.13 (SCL); also elsewhere on the board
/MCU and RX/I2C1_SDA: U5.14 (SDA); also elsewhere on the board
/MCU and RX/VBAT: C11.2, R3.2; also elsewhere on the board
/Sensors/VBAT_DIV: R1.2, R2.1, R3.1
GND: C11.1, C12.2, C13.2, C14.1, J8.3, R2.2, U5.1 (SDO/SA0), U5.2 (SDX), U5.3 (SCX), U5.6 (GND), U5.7 (GND); also elsewhere on the board
unnamed: J8.2, R4.1

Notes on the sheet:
VBAT SENSE
About 0.13*Vbat 2S 8.4V -> 1.09V 4S 16.8V -> 2.19V (4S not supported by drivers)
Voltage diveder with filer for Vbat readout directly with the ADC
CUSTOM ANALOG OR DIGITAL PORT
ACCELEROMETER & GYROSCOPE
5.1K pullup added to mcu schematic (10K from datasheet)
I2C ADD: 1101010b

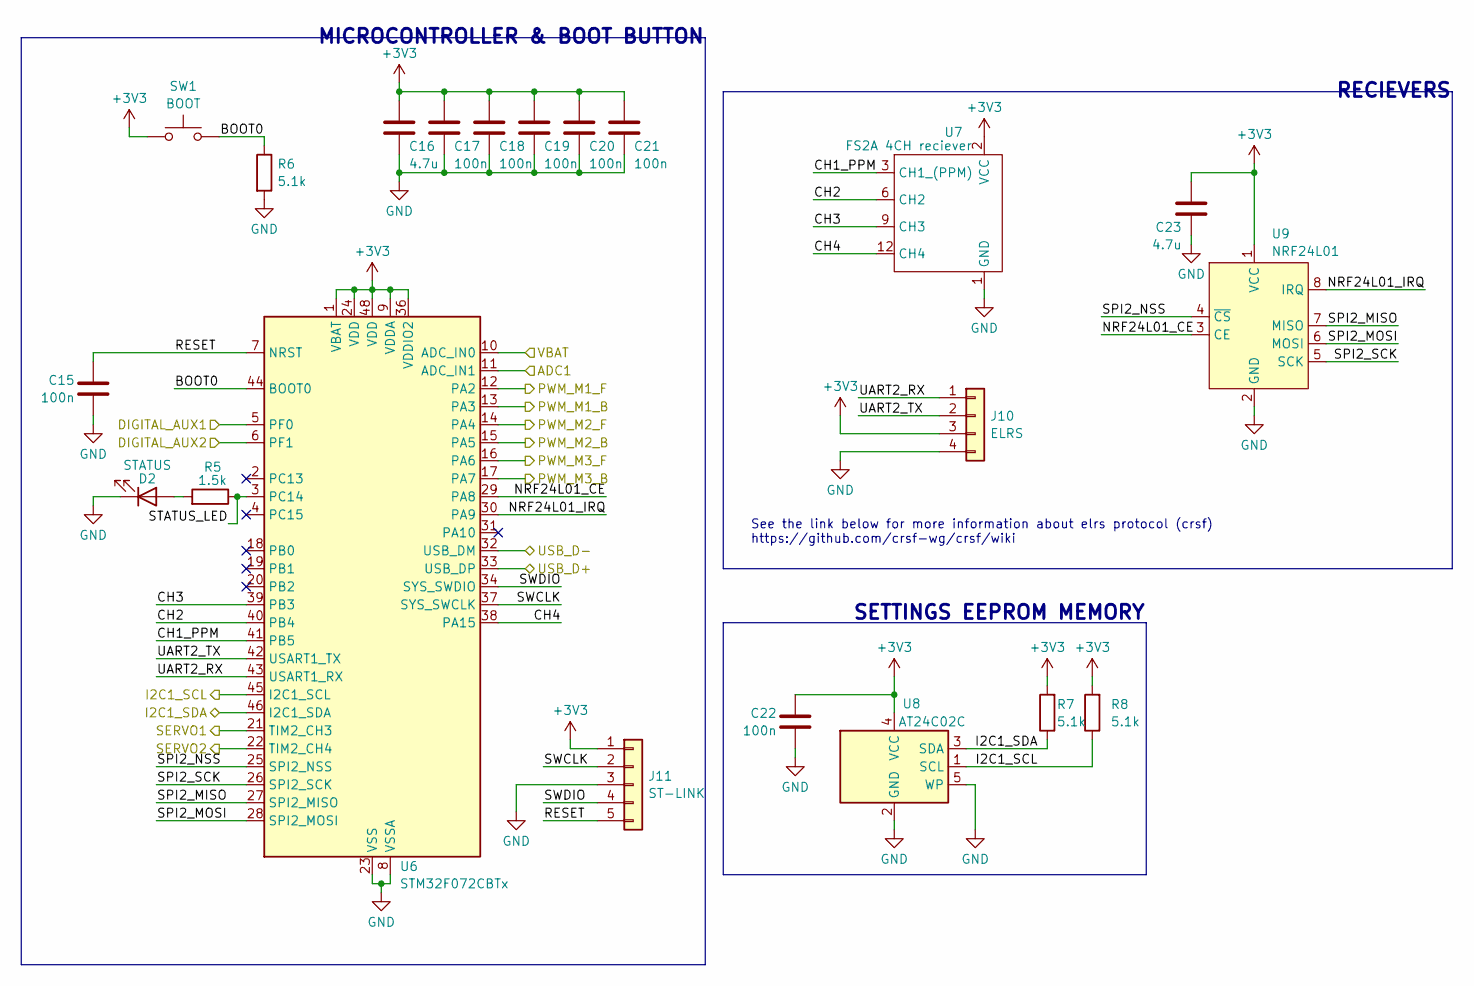
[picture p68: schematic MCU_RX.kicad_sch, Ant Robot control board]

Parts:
C15, C17, C18, C19, C20, C21, C22: 100n; C_0603_1608Metric; LCSC C282519
C16, C23: 4.7u; C_0603_1608Metric; LCSC C2858031
D2: STATUS; LED_0805_2012Metric; LCSC C84259
J10: ELRS; PinSocket_1x04_P2.54mm_Vertical
J11: ST-LINK; PinHeader_1x05_P2.54mm_Vertical
R5: 1.5k; R_0603_1608Metric; LCSC C114668
R6, R7, R8: 5.1k; R_0603_1608Metric; LCSC C23186
SW1: BOOT; SW_SPST_CK_RS282G05A3; LCSC C393942
U6: STM32F072CBTx; LQFP-48_7x7mm_P0.5mm; LCSC C81720
U7: FS2A 4CH reciever
U8: AT24C02C; SOT-23-5; LCSC C7432363
U9: NRF24L01; NRF24L01+ SMD

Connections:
+3V3: C16.1, C17.1, C18.1, C19.1, C20.1, C21.1, C22.1, C23.1, J10.3, J11.1, R7.2, R8.2, SW1.1, U6.1 (VBAT), U6.9 (VDDA), U6.24 (VDD), U6.36 (VDDIO2), U6.48 (VDD), U7.2 (VCC), U7.5, U7.8, U7.11, U8.4 (VCC), U9.1 (VCC); also elsewhere on the board
/DC Motors/PWM_M1_B: U6.13 (PA3); also elsewhere on the board
/DC Motors/PWM_M1_F: U6.12 (PA2); also elsewhere on the board
/DC Motors/PWM_M2_B: U6.15 (PA5); also elsewhere on the board
/DC Motors/PWM_M2_F: U6.14 (PA4); also elsewhere on the board
/DC Motors/PWM_M3_B: U6.17 (PA7); also elsewhere on the board
/DC Motors/PWM_M3_F: U6.16 (PA6); also elsewhere on the board
/MCU and RX/ADC1: U6.11 (ADC_IN1); also elsewhere on the board
/MCU and RX/BOOT0: R6.1, SW1.2, U6.44 (BOOT0)
/MCU and RX/CH1_PPM: U6.41 (PB5), U7.3 (CH1_(PPM))
/MCU and RX/CH2: U6.40 (PB4), U7.6 (CH2)
/MCU and RX/CH3: U6.39 (PB3), U7.9 (CH3)
/MCU and RX/CH4: U6.38 (PA15), U7.12 (CH4)
/MCU and RX/DIGITAL_AUX1: U6.5 (PF0); also elsewhere on the board
/MCU and RX/DIGITAL_AUX2: U6.6 (PF1); also elsewhere on the board
/MCU and RX/I2C1_SCL: R8.1, U6.45 (I2C1_SCL), U8.1 (SCL); also elsewhere on the board
/MCU and RX/I2C1_SDA: R7.1, U6.46 (I2C1_SDA), U8.3 (SDA); also elsewhere on the board
/MCU and RX/NRF24L01_CE: U6.29 (PA8), U9.3 (CE)
/MCU and RX/NRF24L01_IRQ: U6.30 (PA9), U9.8 (IRQ)
/MCU and RX/RESET: C15.1, J11.5, U6.7 (NRST)
/MCU and RX/SERVO1: U6.21 (TIM2_CH3); also elsewhere on the board
/MCU and RX/SERVO2: U6.22 (TIM2_CH4); also elsewhere on the board
/MCU and RX/SPI2_MISO: U6.27 (SPI2_MISO), U9.7 (MISO)
/MCU and RX/SPI2_MOSI: U6.28 (SPI2_MOSI), U9.6 (MOSI)
/MCU and RX/SPI2_NSS: U6.25 (SPI2_NSS), U9.4 (~CS)
/MCU and RX/SPI2_SCK: U6.26 (SPI2_SCK), U9.5 (SCK)
/MCU and RX/STATUS_LED: R5.1, U6.3 (PC14)
/MCU and RX/SWCLK: J11.2, U6.37 (SYS_SWCLK)
/MCU and RX/SWDIO: J11.4, U6.34 (SYS_SWDIO)
/MCU and RX/UART2_RX: J10.1, U6.43 (USART1_RX)
/MCU and RX/UART2_TX: J10.2, U6.42 (USART1_TX)
/MCU and RX/USB_D+: U6.33 (USB_DP); also elsewhere on the board
/MCU and RX/USB_D-: U6.32 (USB_DM); also elsewhere on the board
/MCU and RX/VBAT: U6.10 (ADC_IN0); also elsewhere on the board
GND: C15.2, C16.2, C17.2, C18.2, C19.2, C20.2, C21.2, C22.2, C23.2, D2.1 (K), J10.4, J11.3, R6.2, U6.8 (VSSA), U6.23 (VSS), U6.35 (VSS), U6.47 (VSS), U7.1 (GND), U7.4, U7.7, U7.10, U8.2 (GND), U8.5 (WP), U9.2 (GND); also elsewhere on the board
unnamed: D2.2 (A), R5.2

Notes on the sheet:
RECIEVERS
SETTINGS EEPROM MEMORY
See the link below for more information about elrs protocol (crsf) https://github.com/crsf-wg/crsf/wiki
MICROCONTROLLER & BOOT BUTTON


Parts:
C1, C2, C3: 4.7u; C_0603_1608Metric; VOLTAGE 25V; LCSC C2858031
C4: 4.7u; C_0603_1608Metric; LCSC C2858031
D1: SD103AWS; D_SOD-123; LCSC C181207
J1: USB-C_304A-ACP16X; USB_C_304A-ACP16X
J2: 2s Battery; PinHeader_1x02_P2.54mm_Vertical
TP1: 3V3; TestPoint_THTPad_1.5x1.5mm_Drill0.7mm
TP2: GND; TestPoint_THTPad_1.5x1.5mm_Drill0.7mm
U1: GM7333; SOT-89-3; LCSC C2833582

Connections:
+3V3: C4.1, TP1.1, U1.3 (OUT); also elsewhere on the board
+BATT: C1.1, C2.1, C3.1, D1.1 (K), J2.2, U1.2 (IN); also elsewhere on the board
/MCU and RX/USB_D+: J1.6 (DP1), J1.8 (DP2); also elsewhere on the board
/MCU and RX/USB_D-: J1.5 (DN2), J1.7 (DN1); also elsewhere on the board
/Power/VUSB: D1.2 (A), J1.2 (VBUS), J1.11 (VBUS)
GND: C1.2, C2.2, C3.2, C4.2, J1.1 (GND_1), J1.12 (GND_2), J1.13 (SHIELD), J2.1, TP2.1, U1.1 (GND); also elsewhere on the board

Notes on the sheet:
not needed pull-down resistors for most of the cases
BATTERY CONNECTOR
3.3V LDOs
USB CONNECTOR FOR SETTINGS & FIRMWARE UPDATE
Changed to SD103AWS for the development board

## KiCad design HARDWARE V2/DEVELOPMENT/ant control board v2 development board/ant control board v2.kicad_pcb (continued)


Board: 2 copper layers, 65.0 x 60.0 mm, 101 parts (0 on the bottom side), 46 nets.

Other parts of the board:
kibuzzard-68590DA6: G***; kibuzzard-68590DA6
kibuzzard-68590DB3: G***; kibuzzard-68590DB3
kibuzzard-68590DCB: G***; kibuzzard-68590DCB
kibuzzard-68590DDD: G***; kibuzzard-68590DDD
kibuzzard-68590DE3: G***; kibuzzard-68590DE3
kibuzzard-68590E11: G***; kibuzzard-68590E11
kibuzzard-68590E35: G***; kibuzzard-68590E35
kibuzzard-68590E57: G***; kibuzzard-68590E57
kibuzzard-68590F1F: G***; kibuzzard-68590F1F
kibuzzard-68590F5B: G***; kibuzzard-68590F5B
kibuzzard-68590F79: G***; kibuzzard-68590F79
kibuzzard-68591B9B: G***; kibuzzard-68591B9B
kibuzzard-68591B85: G***; kibuzzard-68591B85
kibuzzard-68591BA5: G***; kibuzzard-68591BA5
kibuzzard-68591BA8: G***; kibuzzard-68591BA8
kibuzzard-685910F4: G***; kibuzzard-685910F4
kibuzzard-685911E8: G***; kibuzzard-685911E8
kibuzzard-685911EF: G***; kibuzzard-685911EF
kibuzzard-685916F6: G***; kibuzzard-685916F6
kibuzzard-6859100F: G***; kibuzzard-6859100F
kibuzzard-6859102F: G***; kibuzzard-6859102F
kibuzzard-6859109F: G***; kibuzzard-6859109F
kibuzzard-6859111F: G***; kibuzzard-6859111F
kibuzzard-6859112C: G***; kibuzzard-6859112C
kibuzzard-6859119B: G***; kibuzzard-6859119B
kibuzzard-6859170A: G***; kibuzzard-6859170A
kibuzzard-68591052: G***; kibuzzard-68591052
kibuzzard-68591071: G***; kibuzzard-68591071
kibuzzard-68591112: G***; kibuzzard-68591112
kibuzzard-68591123: G***; kibuzzard-68591123
kibuzzard-68591131: G***; kibuzzard-68591131
kibuzzard-68591152: G***; kibuzzard-68591152
kibuzzard-68591192: G***; kibuzzard-68591192

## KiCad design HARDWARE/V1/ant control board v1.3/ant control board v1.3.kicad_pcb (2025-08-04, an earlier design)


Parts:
C1, C2: 20p; C_0603_1608Metric; LCSC C91702
C3, C7, C9, C10, C11, C12, C13, C14, C16, C20, C21, C25, C26, C27, C28, C29, C30, C31: 100n; C_0603_1608Metric; LCSC C282519
C4, C8, C15, C19, C23, C24: 4.7u; C_0603_1608Metric; LCSC C307467
C5, C6, C17, C18, C22: 22u; C_0603_1608Metric; LCSC C86295
D1: STATUS; LED_0805_2012Metric; LCSC C84259
D2: SD103AW; D_SOD-123; LCSC C181207
J1: 2s Battery; Pad 02x01
J2: B_SW; Pad 02x01
J4: USB-C_304A-ACP16X; USB_C_304A-ACP16X; LCSC C2909609
J5: custom analog 2; Pad 03x01
J6: custom analog 1; Pad 03x01
J7: servo 2; Pad 03x01
J8: servo 1 (HV); Pad 03x01
J9: M1; Pad 02x01
J10: M2; Pad 02x01
J11: M3; Pad 02x01
JP1: SERVO2 PW; SolderJumper-3_P1.3mm_Open_RoundedPad1.0x1.5mm_NumberLabels
L1: 4.7uH; XRCD43-3R3M; LCSC C3002569
R1, R3, R7: 10k; R_0603_1608Metric; LCSC C103199
R2, R5, R8, R9, R10, R11, R12, R13: 5.1k; R_0603_1608Metric; LCSC C23186
R4: 1k; R_0603_1608Metric; LCSC C103198
R6: 54.9k; R_0603_1608Metric; LCSC C23077
SW1: BOOT; SW-SMD_TS24CA SMD BUTTO 90deg; LCSC C393942
SW2: RESET; SW-SMD_TS24CA SMD BUTTO 90deg; LCSC C393942
TP1: RST; TestPoint_Pad_D1.0mm
TP2: SWDIO; TestPoint_Pad_D1.0mm
TP3: SWCLK; TestPoint_Pad_D1.0mm
TP4: 3V3; TestPoint_Pad_D1.0mm
TP5: GND; TestPoint_Pad_D1.0mm
U1: TPS563200; SOT-23-6; LCSC C97253
U2: STM32F070CBTx; LQFP-48_7x7mm_P0.5mm; LCSC C74909
U3: H7233-1; SOT-23-3; LCSC C277859
U4: FS2A 4CH reciever
U5, U6, U7: DRV8838; WSON-8-1EP_2x2mm_P0.5mm_EP0.9x1.6mm; LCSC C86667
U8, U9: 74LVC1T45DW-7; SOT-363_SC-70-6; LCSC C168855
U10: AT24C02C; SOT-23-5; LCSC C7432363
Y1: TAXM8M4RLBDDT2T; Crystal_SMD_3225-4Pin_3.2x2.5mm; LCSC C720915

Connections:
+3V3: C8.1, C9.1, C10.1, C11.1, C12.1, C13.1, C15.1, C16.1, C22.1, C25.1, C26.1, C27.1, C31.1, J5.1, J6.1, R13.1, SW1.1, TP4.1, U2.1 (VDD), U2.9 (VDDA), U2.24 (VDD), U2.36 (VDD), U2.48 (VDD), U3.2 (VO), U4.2 (VCC), U4.5, U4.8, U4.11, U5.8 (VCC), U6.8 (VCC), U7.8 (VCC), U8.6 (VCCB), U9.6 (VCCB), U10.4 (VCC)
+5V: C17.1, C18.1, C21.1, J7.2, JP1.3 (B), L1.2, R6.1, U3.3 (VI), U8.1 (VCCA), U9.1 (VCCA)
+BATT: C5.1, C6.1, C7.1, C19.1, C20.1, C28.1, C29.1, C30.1, D2.1 (K), J1.2, JP1.1 (A), R1.1, U1.3 (VIN), U1.5 (EN), U5.1 (VM), U6.1 (VM), U7.1 (VM)
/ADC1: C24.2, R11.2, U2.11 (PA1)
/ADC2: C23.2, R10.2, U2.12 (PA2)
/BAT_2_SW: J1.1, J2.2
/BOOT0: R12.1, SW1.2, U2.44 (BOOT0)
/CC1: J4.4 (CC1), R8.1
/CC2: J4.10 (CC2), R9.1
/CH1_PPM: U2.18 (PB0), U4.3 (CH1_(PPM))
/CH2: U2.19 (PB1), U4.6 (CH2)
/CH3: U2.20 (PB2), U4.9 (CH3)
/CH4: U2.39 (PB3), U4.12 (CH4)
/I2C1_SCL: U2.45 (I2C1_SCL), U10.1 (SCL)
/I2C1_SDA: U2.46 (I2C1_SDA), U10.3 (SDA)
/M1+: J9.1, U5.2 (OUT1)
/M1-: J9.2, U5.3 (OUT2)
/M1_DIR: U2.28 (PB15), U5.6 (PH)
/M1_PWM: U2.29 (PA8), U5.5 (EN)
/M2+: J10.1, U6.2 (OUT1)
/M2-: J10.2, U6.3 (OUT2)
/M2_DIR: U2.26 (PB13), U6.6 (PH)
/M2_PWM: U2.30 (PA9), U6.5 (EN)
/M3+: J11.1, U7.2 (OUT1)
/M3-: J11.2, U7.3 (OUT2)
/M3_DIR: U2.22 (PB11), U7.6 (PH)
/M3_PWM: U2.31 (PA10), U7.5 (EN)
/OSC_IN: C1.1, U2.5 (RCC_OSC_IN), Y1.1
/OSC_OUT: R4.2, U2.6 (RCC_OSC_OUT)
/RESET: C3.1, R13.2, SW2.2, TP1.1, U2.7 (NRST)
/SERVO_1_SIG: U2.42 (PB6), U9.4 (B)
/SERVO_1_SIG_5V: J8.1, U9.3 (A)
/SERVO_2_SIG: U2.43 (PB7), U8.4 (B)
/SERVO_2_SIG_5V: J7.1, U8.3 (A)
/SW: C14.2, L1.1, U1.2 (SW)
/USB_D+: J4.6 (DP1), J4.8 (DP2), U2.33 (USB_DP)
/USB_D-: J4.5 (DN2), J4.7 (DN1), U2.32 (USB_DM)
/VBAT: C4.2, R3.2, U2.10 (PA0)
/VBAT_DIV: R1.2, R2.1, R3.1
/VFB: R6.2, R7.1, U1.4 (VFB)
/VUSB: D2.2 (A), J4.2 (VBUS), J4.11 (VBUS)
/~M1_SLEEP: U2.27 (PB14), U5.7 (~SLEEP)
/~M2_SLEEP: U2.25 (PB12), U6.7 (~SLEEP)
/~M3_SLEEP: U2.21 (PB10), U7.7 (~SLEEP)
GND: C1.2, C2.2, C3.2, C4.1, C5.2, C6.2, C7.2, C8.2, C9.2, C10.2, C11.2, C12.2, C13.2, C15.2, C16.2, C17.2, C18.2, C19.2, C20.2, C21.2, C22.2, C23.1, C24.1, C25.2, C26.2, C27.2, C28.2, C29.2, C30.2, C31.2, D1.1 (K), J2.1, J4.1 (GND_1), J4.12 (GND_2), J4.13 (SHIELD), J5.3, J6.3, J7.3, J8.3, R2.2, R7.2, R8.2, R9.2, R12.2, SW1.3 (hold), SW1.4 (hold), SW2.1, SW2.3 (hold), SW2.4 (hold), TP5.1, U1.1 (GND), U2.8 (VSSA), U2.23 (VSS), U2.35 (VSS), U2.47 (VSS), U3.1 (GND), U4.1 (GND), U4.4, U4.7, U4.10, U5.4 (GND), U5.9 (GND), U6.4 (GND), U6.9 (GND), U7.4 (GND), U7.9 (GND), U8.2 (GND), U8.5 (DIR), U9.2 (GND), U9.5 (DIR), U10.2 (GND), U10.5 (WP), Y1.2, Y1.4
unnamed: C2.1, R4.1, Y1.3
unnamed: D1.2 (A), R5.1
unnamed: J5.2, R10.1
unnamed: J6.2, R11.1
unnamed: J8.2, JP1.2 (C)
unnamed: C14.1, U1.6 (VBST)
unnamed: TP2.1, U2.34 (PA13)
unnamed: TP3.1, U2.37 (PA14)
unnamed: R5.2, U2.4 (PC15)

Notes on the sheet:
TO USE 1S BATTERY SHORT ALL 3 CONNECTIONs (for 1S usage, the buck converter is not needed)
About 1/3 Vbat 8.4V -> 2.837V
Voltage diveder with filer for Vbat readout directly with the ADC
BUCK CONVERTER



Board: 2 copper layers, 22.8 x 33.2 mm, 96 parts (53 on the bottom side), 54 nets.

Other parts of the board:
kibuzzard-66A643AC: G***; kibuzzard-66A643AC
kibuzzard-66A6444D: G***; kibuzzard-66A6444D
kibuzzard-66AE2B42: G***; kibuzzard-66AE2B42
kibuzzard-667D9F0F: G***; kibuzzard-667D9F0F
kibuzzard-667D9F2A: G***; kibuzzard-667D9F2A
kibuzzard-667D9F03: G***; kibuzzard-667D9F03
kibuzzard-667D9F7E: G***; kibuzzard-667D9F7E
kibuzzard-667D9F8D: G***; kibuzzard-667D9F8D
kibuzzard-667D9F19: G***; kibuzzard-667D9F19
kibuzzard-667D9F22: G***; kibuzzard-667D9F22
kibuzzard-667D9F56: G***; kibuzzard-667D9F56
kibuzzard-667D9F87: G***; kibuzzard-667D9F87
kibuzzard-667D9F91: G***; kibuzzard-667D9F91
kibuzzard-667D9F97: G***; kibuzzard-667D9F97
kibuzzard-667D9FA0: G***; kibuzzard-667D9FA0
kibuzzard-667D9FA9: G***; kibuzzard-667D9FA9
kibuzzard-667D9FAD: G***; kibuzzard-667D9FAD
kibuzzard-667D9FB5: G***; kibuzzard-667D9FB5
kibuzzard-669B8C44: G***; kibuzzard-669B8C44
kibuzzard-669B8939: G***; kibuzzard-669B8939

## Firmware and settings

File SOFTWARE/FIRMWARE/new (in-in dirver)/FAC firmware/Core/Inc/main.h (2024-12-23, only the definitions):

#define U_LED_Pin GPIO_PIN_15
#define U_LED_GPIO_Port GPIOC
#define VBAT_Pin GPIO_PIN_0
#define VBAT_GPIO_Port GPIOA
#define POT1_Pin GPIO_PIN_1
#define POT1_GPIO_Port GPIOA
#define POT2_Pin GPIO_PIN_2
#define POT2_GPIO_Port GPIOA
#define CH1_Pin GPIO_PIN_0
#define CH1_GPIO_Port GPIOB
#define CH1_EXTI_IRQn EXTI0_1_IRQn
#define CH2_Pin GPIO_PIN_1
#define CH2_GPIO_Port GPIOB
#define CH2_EXTI_IRQn EXTI0_1_IRQn
#define CH3_Pin GPIO_PIN_2
#define CH3_GPIO_Port GPIOB
#define CH3_EXTI_IRQn EXTI2_3_IRQn
#define SLEEPN_M3_Pin GPIO_PIN_10
#define SLEEPN_M3_GPIO_Port GPIOB
#define PWM_M3_B_Pin GPIO_PIN_11
#define PWM_M3_B_GPIO_Port GPIOB
#define SLEEPN_M2_Pin GPIO_PIN_12
#define SLEEPN_M2_GPIO_Port GPIOB
#define PWM_M2_B_Pin GPIO_PIN_13
#define PWM_M2_B_GPIO_Port GPIOB
#define SLEEPN_M1_Pin GPIO_PIN_14
#define SLEEPN_M1_GPIO_Port GPIOB
#define PWM_M1_B_Pin GPIO_PIN_15
#define PWM_M1_B_GPIO_Port GPIOB
#define PWM_M1_F_Pin GPIO_PIN_8
#define PWM_M1_F_GPIO_Port GPIOA
#define PWM_M2_F_Pin GPIO_PIN_9
#define PWM_M2_F_GPIO_Port GPIOA
#define PWM_M3_F_Pin GPIO_PIN_10
#define PWM_M3_F_GPIO_Port GPIOA
#define CH4_Pin GPIO_PIN_3
#define CH4_GPIO_Port GPIOB
#define CH4_EXTI_IRQn EXTI2_3_IRQn
#define SERVO1_HV_Pin GPIO_PIN_6
#define SERVO1_HV_GPIO_Port GPIOB
#define SERVO2_Pin GPIO_PIN_7
#define SERVO2_GPIO_Port GPIOB
#define TRUE 1
#define FALSE 0
#define NUMBER_OF_PPM_CHANNEL 8
#define S1_MIN_TIME_PWM	1000
#define S1_MAX_TIME_PWM	2000
#define S2_MIN_TIME_PWM	544
#define S2_MAX_TIME_PWM	2400
#define CUTOFF_BATTERY_TIMEOUT 10	// seconds at witch the battery must be below the minimum to be declared empty

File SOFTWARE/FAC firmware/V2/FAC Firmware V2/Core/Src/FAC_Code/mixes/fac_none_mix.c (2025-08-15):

/*
 * fac_none_mix.c
 *
 *  Created on: Aug 14, 2025
 *      Author: filippo-castellan
 */

#include "FAC_Code/mixes/fac_none_mix.h"

static Nonemix noneMix;

/* STATIC FUNCTION PROTORYPES */
static void FAC_none_mix_SET_dead_zone(uint8_t deadzone);
static void FAC_none_mix_SET_motor_channel(uint8_t motorNumber, uint8_t channel);
static void FAC_none_mix_SET_servo_channel(uint8_t servoNumber, uint8_t channel);
static uint8_t FAC_none_mix_GET_motor_channel(uint8_t motorNumber);
static uint8_t FAC_none_mix_GET_servo_channel(uint8_t servoNumber);

/* FUNCTION DEFINITION */
/* ----------------------PRIVATE FUNCTIONS---------------------- */

static void FAC_none_mix_SET_dead_zone(uint8_t deadzone) {
	noneMix.dead_zone = deadzone;
}

static void FAC_none_mix_SET_motor_channel(uint8_t motorNumber, uint8_t channel) {
	if (motorNumber > MOTORS_NUMBER)
		return;	// this motor does not exist
	noneMix.motors_channels[motorNumber - 1] = channel;
}

static void FAC_none_mix_SET_servo_channel(uint8_t servoNumber, uint8_t channel) {
	if (servoNumber > SERVOS_NUMBER)
		return;	// this servo does not exist
	noneMix.servos_channels[servoNumber - 1] = channel;
}

static uint8_t FAC_none_mix_GET_motor_channel(uint8_t motorNumber) {
	if (motorNumber > MOTORS_NUMBER)
		return 0;	// this motor does not exist
	return noneMix.motors_channels[motorNumber - 1];
}

static uint8_t FAC_none_mix_GET_servo_channel(uint8_t servoNumber) {
	if (servoNumber > SERVOS_NUMBER)
		return 0;	// this servo does not exist
	return noneMix.servos_channels[servoNumber - 1];
}
/* ----------------------PUBBLIC FUNCTIONS---------------------- */
uint8_t FAC_none_mix_GET_dead_zone() {
	return noneMix.dead_zone;
}

/**
 * @biref	Update the motors/servos speeds/positions
 * @note	This function directly apply the settings on the motor/servos
 * @time	Max execution time: ~8.25ms
 */
void FAC_none_mix_update() {
	/* get receiver values */
	int16_t channels[8];
	for (int i = 1; i <= 8; i++) {
		channels[i - 1] = FAC_std_receiver_GET_channel(i);
	}

	/* center the value for motors */
	for (int i = 1; i < 8; i++) {	// run across all channel
		for (int j = 1; j <= MOTORS_NUMBER; j++) {	// run across all motors
			if (i == FAC_none_mix_GET_motor_channel(j)/*noneMix.motors_channels[j - 1]*/) {	// check if the motor is associated to this channel
				channels[i - 1] = (channels[i - 1] - (RECEIVER_CHANNEL_RESOLUTION - 1) / 2) * 2;// center the value of the channel if it is associated to a motor
				channels[i - 1] = FAC_mix_calculate_dead_zone(channels[i - 1], noneMix.dead_zone, -(RECEIVER_CHANNEL_RESOLUTION - 1), RECEIVER_CHANNEL_RESOLUTION - 1);	// calculate also the deadzone
				/* calculate the direction */
				uint8_t dir;
				if (channels[i - 1] > 0)
					dir = FORWARD;
				else
					dir = BACKWARD;
				/* set the new motor speed */
				FAC_motor_set_speed_direction(j, dir, abs(channels[i - 1]));
			}
		}
		for (int j = 1; j <= SERVOS_NUMBER; j++) {	// run across all servos
			if (i == FAC_none_mix_GET_servo_channel(j)/*noneMix.servos_channels[j - 1]*/) {	// check if the servo is associated to this channel
				channels[i-1] = FAC_mix_calculate_dead_zone(channels[i - 1], noneMix.dead_zone, 0, RECEIVER_CHANNEL_RESOLUTION - 1);// calculate deadzone
				/* set the new servo position */
				FAC_servo_set_position(j, channels[i - 1]);
			}
		}
	}
}

/*
 * @brief	  	The initialization used when no mixes are active
 * @IMPORTANT 	!! MUST BE CALLED IF NEW SETTINGS ARE LOADED !!
 * @note	 	Channels are connected following the initialization
 */
void FAC_none_mix_init(uint8_t deadzone, uint8_t m1Ch, uint8_t m2Ch, uint8_t m3Ch, uint8_t s1Ch, uint8_t s2Ch) {
	FAC_none_mix_SET_dead_zone(deadzone);
	FAC_none_mix_SET_motor_channel(1, m1Ch);
	FAC_none_mix_SET_motor_channel(2, m2Ch);
	FAC_none_mix_SET_motor_channel(3, m3Ch);

	FAC_none_mix_SET_servo_channel(1, s1Ch);
	FAC_none_mix_SET_servo_channel(2, s2Ch);
}

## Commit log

2024-08-26 updated hardware files
    [ant control board v1.3.kicad_pcb]
2024-08-28 Updated the back silkscreen of the power conector
    + and - were inverted on the back silckscreen
    [ant control board v1.3-B_Cu.gbr, ant control board v1.3-B_Mask.gbr, ant control board v1.3-B_Paste.gbr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]
2024-09-05 Fixed limit and cutoff functions
    limit and cutoff function now affect also S1 assumed conected to the weapon ESC
    Updated also blinking timing for varius operation mode:
    4s perdiod for normal operation
    750ms period for limit
    200ms period for cutoff
    [main.c]
2024-09-05 Fixed arming via dedicated channel
    Now can arm and disarm the robot with the dedicated channel
    (previously when armed can not be disarmed any more)
    [main.c]
2024-09-11 Added deadzone, removed weapon ch from arming check, no servo PWM when disarmed
    Added deadzone for servos and DC motors, removed the weapon channle check for arming (without dedicated channel for arming), now when disarmed PWM signal for servos are not generated
2024-10-11 Live status UPDATE
    STATUS command added to the FAC firmware 1.4 (needs more test). Added the compatibiliy to the settings tool, but it became laggy. Must try to use multiple treads for main application and all serial things. there is a problem understanding the status comand, needs some fixes
    [main.c, settings.c, settings.h]
2024-11-24 fixed the no tank mix problem
    without using the tank mix FAC should control individual DC motors directly using the remote controller channel's value, but it did't. Now it does (the error was not passing the enum number)
    [ant control board v1.3.kicad_pcb]
2024-11-25 Updated reciever function for non aligned signals from reciever PWM
2024-12-23 Added IN-IN support for DRV8837 driver
    in the new version for IN-IN controlled motor driver (like drv8837) the pwm signals are generated from the DMA (no cpu usage)
2024-12-23 fixed some bux for the unidirectional dc motor function
    [motor.c]
2024-12-23 same firmware support IN-IN & PH-EN motor driver. PWM steps up to 1000
2024-12-24 fixed servo pwm
    the problem was that some functions was following the fixed 100 steps not the variable speed_steps
    [motor.c, servo.c]
2025-08-04 new version of code and hardware
    now a new hardware is here, complete redo of hardware and software. First commit with all files, part of the code is already written
    [MCU_RX.kicad_sch, ant control board v1.0.kicad_pcb, ant control board v1.0.kicad_sch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]
2025-08-04 created servo.h and .c
    next step: continue to code it
2025-08-04 updated servo.c and .h
2025-08-06 Servo completed, fixed PWM recever
    Completed the controll of servos with custom min and max pulse width. Fixed a problem with the calculation of channels value in PWM mode
    [main.c]
2025-08-14 Added first mix (tankmix) deadzone not made yet on it
    next step implement deadzone on mix
    [ant control board v1.1.csv, ant control board v1.3.csv]
2025-08-14 added "none mix" mix, fixed a bug on servo set position. Now also servo 2 works fine
    next thing is to make non mix configurable, something like decide wich motor/servo is associated at witch channel. How it is now (fixed channel has fixed motors) does not work for a real situation
    [fac_none_mix.c, fac_tank_mix.c, main.c]
2025-08-15 made non mix fully configurable, fixed an error on deadzone calculation
    added also the execution time for non mix and tank mix.
    [FAC Firmware V2.ioc, fac_none_mix.c, fac_tank_mix.c]
2025-09-11 added deadzone, motor freq change and eeprom stored settings.
    tryed to make sound but need some fix it doesn't soung laud enought
    [main.c]
2025-09-12 Made the motor noise working, added jingles, added FAC_app status logic
    [main.c]
2025-09-14 Fixed a bug on servo set/get min max value, added apply usb comand , added settings depedency on init of modules
2025-09-17 Modified tank mix algorithm, added imu code (working)
    The imu makes a simple gyro offset calibration after the trasmitter is powered on
2025-09-18 Fixed telemetry now have accelerometer axes, added execution time main loop
    [FAC Firmware V2.ioc, main.c]
2025-09-19 layout 2.0 facv2 done
    [BOM ant control board v2.csv, MCU_RX.kicad_sch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]
2025-09-21 adjusted some strace position and teardrops. Fixed silkscreedn
    [BOM FAC V2.0.csv, BOM ant control board v2.csv, MCU_RX.kicad_sch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]
2025-09-28 Updated BOM, added some images
    [BOM FAC V2.0.csv, ant control board v2.kicad_pcb, power.kicad_sch]
2025-10-28 Adjusted some pcb things and re generated Prouction files
    [MCU_RX.kicad_sch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]
2025-10-28 forgot to save schematic
2025-11-01 added 0.5s watchdog, and fixed a bug on motorInit
    MotorInit bug was on the index of settings getted on the for loop, "-1"is added.
    Now watchdog works, 0.5s is more than enouth to make a complete loop (20ms shoud be the loop time depends on the active mix)
    [FAC Firmware V2.ioc, main.c]
2025-11-26 Fixed an IMU bug while reading multiple address. Remeber to use the correct WHO_AM_I value (clones has different one, this is original)
    The error was in the device address, sometimes shifting to the left sometimes not, now the address is the one indicated on the datasheet and is shifted every time it is used.
    [ant control board v2.kicad_pcb, ant control board v2.step]
2025-12-07 Fixed firmware, edited pcb layout, prepared all folders for main merge
    FWR update:
    - fixed cutoff algolrithm
    - added respose to all the settings commands
    HWR update:
    - fixed some position of the graphics and capacitores
    [BOM FAC V2.0.csv, BOM FAC V2.1.csv, MCU_RX.kicad_sch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]
2025-12-28 fixed battery type bug, and added telemetry simulation for factool development
2026-01-11 old file
    [FAC v2.1 with FS2A.step, ant control board v2.kicad_pcb]
2026-02-17 added auto calibration vbat read, to fix adding intvref to calculate the vcca and scale the readings
    [main.c]
2026-02-28 Added Vrefint adc calibration for a better vbat readings. Created new jingle composer
    Gingle composer can be found on tools folder
2026-03-14 Require receiver connected before arming
    Add receiver connection tracking and gating for arming, plus version/tag bump.
    - Add receiver.connected flag, FAC_std_receiver_GET_is_connected() and FAC_std_receiver_is_connected() to detect if any Rx channel is non-zero. Init sets connected = FALSE and the previous blocking s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
    - Update main loop so the FAC can only arm if the receiver is detected as connected; preserve behavior when no arming channel is configured.
    - Bump FIRMWARE_VERSION_PATCH to 7 and add FIRMWARE_VERSION_TAG; use the tag when initializing settings (FAC_settings_init).
    - Add DEBUG macro entry to .cproject so serial debug can be conditionally enabled.
    - Docs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
2026-07-26 Convert FIRMWARE V2/FAC-Firmware-V2 into a git submodule
    History for the folder was preserved via git subtree split and pushed
    to https://github.com/FloppyO1/FAC-V2-Firmware.git, then the folder
    was replaced with a submodule pointing to that repository.
    [main.c, main.h]
2026-07-26 git submodule and new bom
    [BOM FAC V2.1 (NO LED).csv]
2026-08-08 mix editor: channel domain becomes symmetric, -1000 .. +1000
    Mirrors the firmware fix. The store clamp is now a no-op in practice, so a mix
    input reaches +1000 and the stick centre is exact. The four stages stay modelled
    separately - collapsing them would either double-apply the deadzone or invent
    travel the hardware does not have.
    The device end is modelled too, mirroring fac_mapper.c instead of approximating
    it: SIM.servoPosition is m_to_range(v, 0, MAX_SERVO_VALUE) -> 0..999 and
    SIM.motorSpeed is the identity on abs(v) -> 0..1000. The Robot tab shows both the
    normalized value and the device units, and the canvas horns and bars follow the
    same two functions.
    Self-test: full positive trav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
2026-08-08 mix editor: a collapsed group follows the cursor while it is dragged
    The members of a collapsed group are not rendered - renderNodes() skips them
    through isHidden() and draws one box carrying data-grp instead - so the
    per-frame '.node[data-id=...]' lookup in the move branch matched nothing, the
    box stayed put, and the group only jumped into place on the refreshAll() at
    mouseup.
    A move drag now resolves the elements it will touch ONCE, at mousedown, into
    dragState.doms (nodes) and dragState.boxes (collapsed boxes). The box tracks
    min(x), min(y) of its members, the same rule renderNodes() uses, so it lands
    where the cursor released it and expanding afterwards shows the members at the
    offsets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
2026-08-08 mix editor: marquee selection sticks, and shows what it will take
    The marquee itself always worked. The click listener on #viewport fired AFTER
    the mouseup that completed it, saw e.target as #viewport or #world, and wiped
    the selection it had just built - which is exactly why releasing over a node or
    a wire kept the selection and releasing over empty canvas did not. That listener
    is gone; an empty canvas press already clears in the mousedown path, so nothing
    was lost, and a few pixels of dead zone keep a shaky click reading as a click.
    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
2026-08-08 mix editor: right button drag pans
    Pan is decided before the port and node branches, so a middle or right
    press landing on a block pans instead of starting a move drag. The
    browser context menu is suppressed inside the canvas only, and bare
    letter shortcuts are gated on no modifier so Ctrl+F reaches the browser.
2026-08-08 mix editor: the four splitters actually resize the panes
    Wire all four splitters with pointer capture, min/max and double-click
    reset; give the palette and right column the collapse toggle the bottom
    panel already had. Pane sizes, collapse state, compact density and grid
    persist in facmix.layout.v1, never in the project file.
2026-08-08 mix editor: auto layout, and prose fields get the full inspector width
    Layout button and L arrange the graph left to right by rank: collapsed
    groups move as one unit, sinks go last, unconnected blocks trail, one
    pushUndo. Description and note now put their label above a full-width
    control.
2026-08-08 mix editor: a Blocks tab generated from the catalogue
    One card per NODES entry: ports, parameters, divisions, proven range and
    the real C, obtained by calling the block's own emit() on a throwaway
    context. The filter bar is built once and only the list re-renders, so
    typing into it does not destroy the input. The receiver chain, the group
    semantics and the cost model move out of the help modal into the tab.
2026-08-09 mix editor: §8 complete — robot view with closed-loop IMU; fix loadProject defaulting bug (migrateProject)
2026-08-10 imu noise for sim added
2026-08-10 mix editor: §1 the robot becomes a layout - chassis, wheels, devices, IMU position mix editor: §2 planar kinematics from the wheels, IMU off-centre, new renderer mix editor: §3 the layout editors - n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
2026-08-12 mix editor: the layout editor — full-screen CAD interface for geometry with grid snap, mm/cm boundary, and independent view controls
    - One mapping (robotViewMap), two poses: panel follows the robot, editor pins it at origin with own zoom/pan
    - Layout grid saved with project (P.sim.robot.gridMm), snaps drags, bypassed by Ctrl
    - Geometry fields in mm; model stays cm — boundary in robotGeomSet/Get, nowhere else
    - Small panel now read-only; only editor's canvas is draggable
    - Geometry card moves (never copies) between tab and editor
    - 413 assertions, all passing; codegen identical to HEAD
2026-08-15 mix editor: levelled IMU frame, rendered registration guide, one mapper ceiling, and a ready-made PID block with gain ports
    - SECTION: IMU FRAME - fac_imu.c ported in integers: the calibrated world
    frame is built at arming (not boot), 7 new imuLevel blocks plus
    imu_calibrated, the simulator arms/recalibrates on reset and on every
    disarm end, mountRoll/Pitch/YawDeg + tiltRoll/PitchDeg make the model
    testable at non-flat attitudes
    - SECTION: MARKDOWN - the registration guide renders as markdown instead of
    a raw <pre>, escape-first pure string->string renderer, no library
    - regCountsHtml/Wire - one enum-count control shared by the Registration tab
    and the Export modal, annotated wit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

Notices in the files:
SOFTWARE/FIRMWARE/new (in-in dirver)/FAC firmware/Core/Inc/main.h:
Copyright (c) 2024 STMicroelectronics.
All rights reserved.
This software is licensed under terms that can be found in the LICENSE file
